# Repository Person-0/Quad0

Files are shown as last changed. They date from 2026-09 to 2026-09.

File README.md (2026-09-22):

# **Quad0**

*quadcopter with a custom flight controller, firmware that supports both brushed and brushless motors*

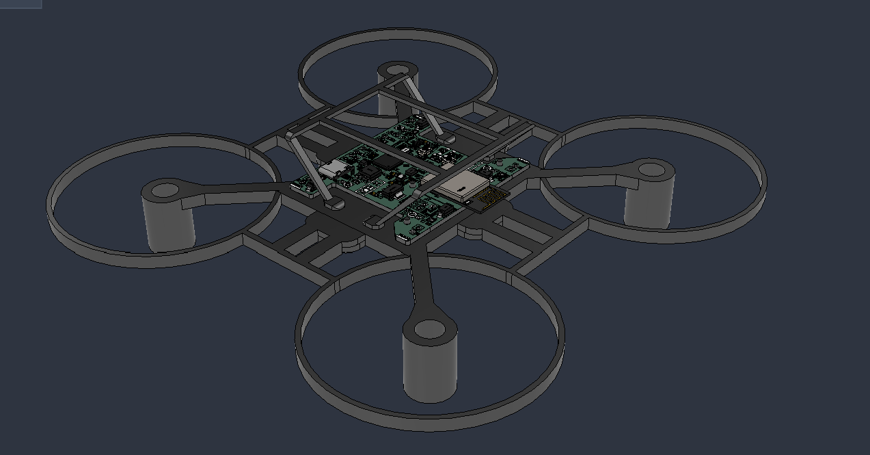
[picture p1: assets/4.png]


## **The Idea**
This is a custom flight controller with minimal stuff required to fly a quadcopter on-board, supporting both brushless and brushed motors.

Onboard components include:

- `RP2350A` Microcontroller Unit
- **IMU**:
    - `ICM-42688-P` Accelerometer & Gyroscope
    - `DPS368XTSA1` Barometer
    - `BMM150` Magnetometer

- MOSFET motor drivers (`DMN2024UFDF-7`) for brushed motors
- Pads to connect brushed / brushless motors
- Support for `ESP01 WiFi module` for brushed mode OR any radio receiver that supports SBUS or similar protocols for brushless mode

The board will be designed in a way such that it can fly with standard *8520 coreless motors* and a tiny lipo battery for brushed mode.

As for the brushless mode, I will be targeting `2204` size brushless motors with a `5inch` prop size, ~5inch frame configuration.

> For building, skip to [Build instructions](#build-instructions) section.

## **PCB**

The PCB 3D preview looks like this:

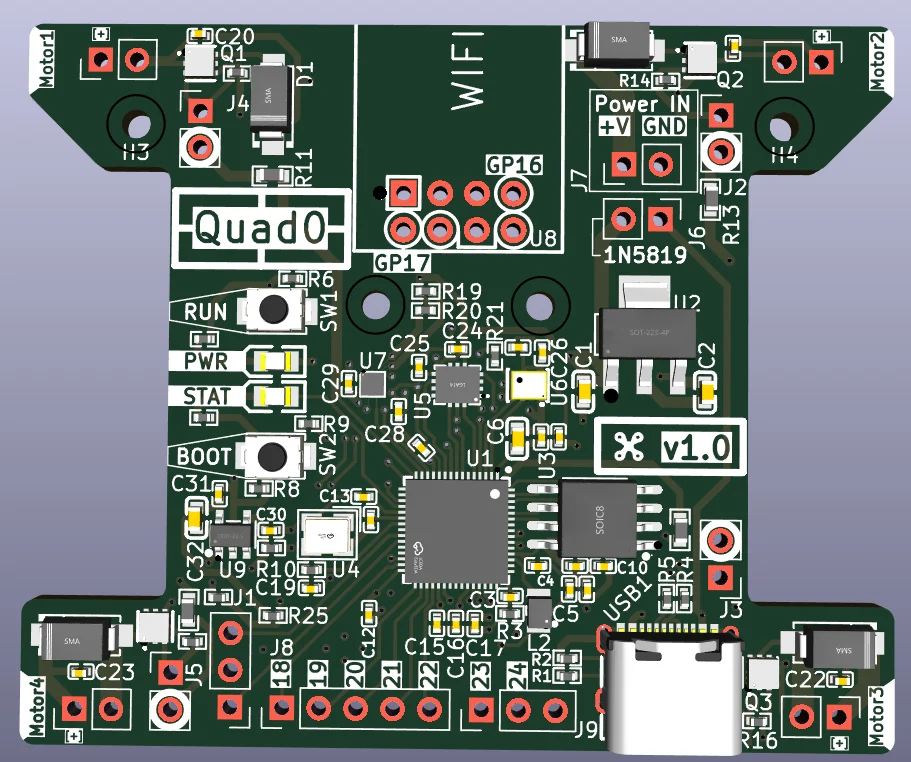
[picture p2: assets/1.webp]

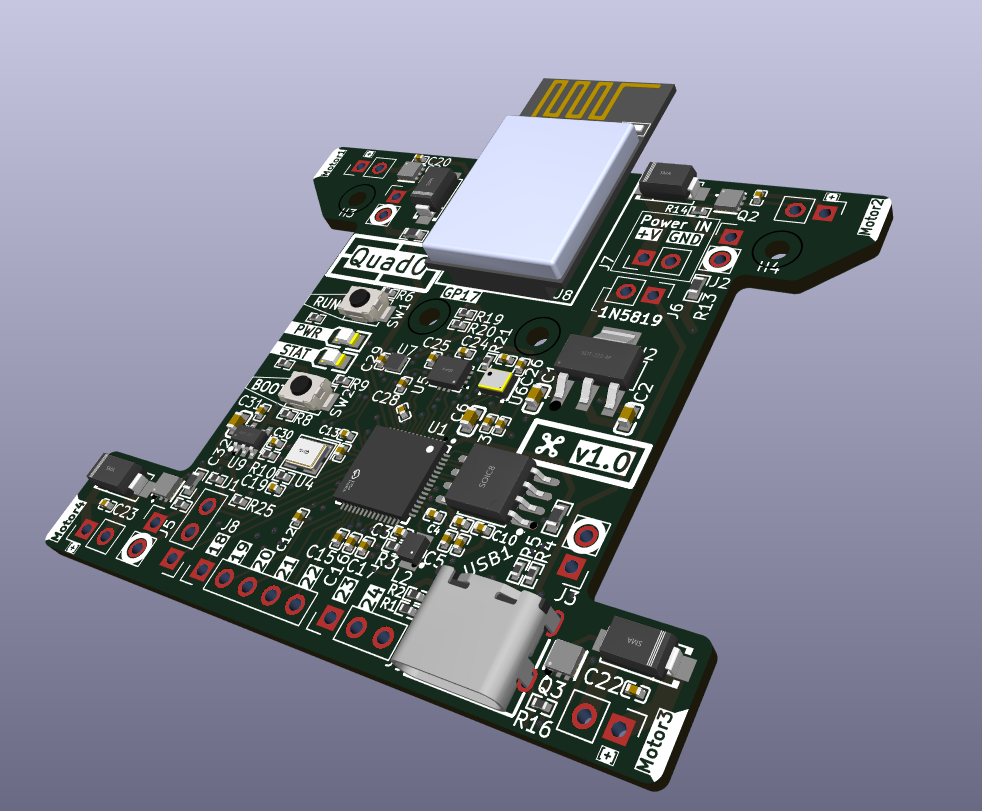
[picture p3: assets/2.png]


## **Schematics**

> *[Right Click >> Open in new tab] on the image to view properly.*

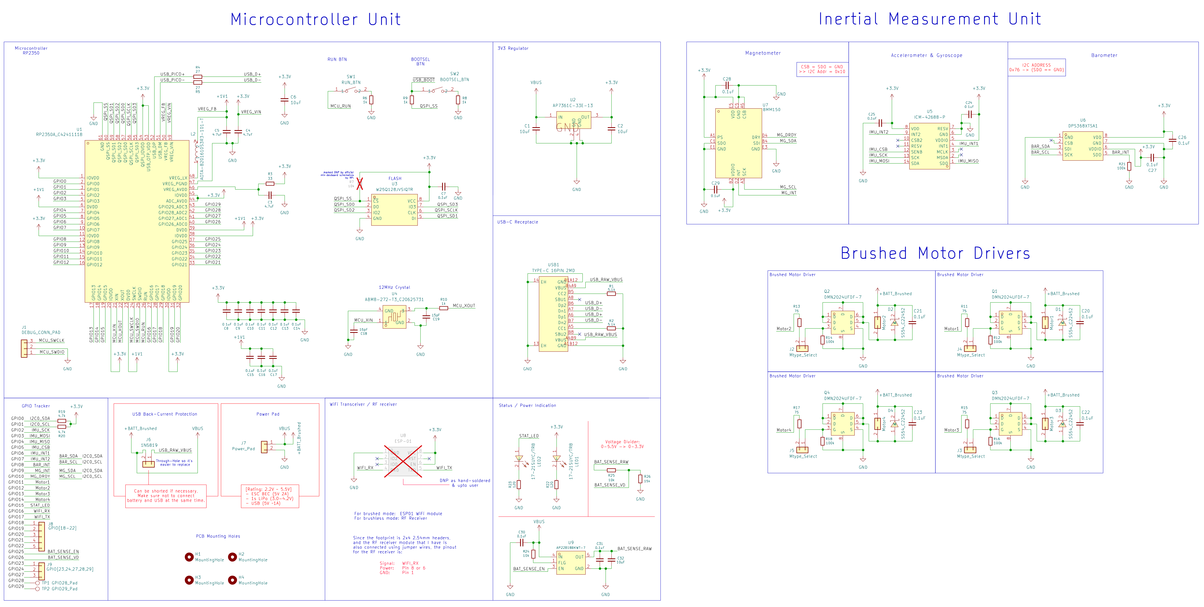
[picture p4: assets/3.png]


> Note that the PCB and schematic files can be opened using KiCAD. They are located in the `/PCB/Quad0` directory inside this repository.

Steps for viewing the PCB schematics and layout:
- Open KiCAD
- Click **File** (top left) >> **Open Project**
- Navigate to the the repository's saved destination,
- Open **/PCB/Quad0** directory
- Select the file `Quad0.kicad_pro`

## Brushed / Brushless Switch

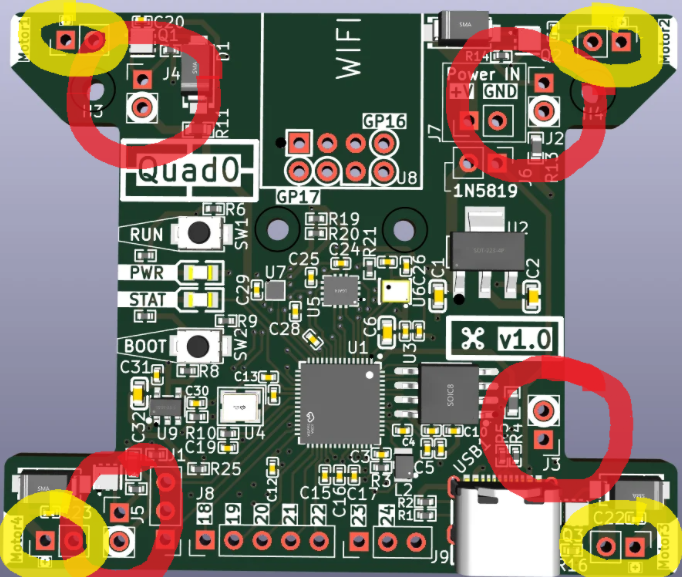
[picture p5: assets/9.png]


- **Yellow**: Brushed motor connectors
- **Red**: Brushed / Brusheless Mode selection connector

**For Brushed:** Short both pads together using solder or by soldering 2.54mm headers and adding jumper.

**For Brushless:** Un-short both pads if shorted, connect ESC signal pin to the pad marked with the thick white circle.

Each Mode selection connector is placed closest to the motor output it controls.

## **CAD Frame**
> View [/CAD](./CAD/) directory for `.f3d` and `.step` files.

The frame for brushed version of the quadcopter was designed in Fusion360 and looks like this:


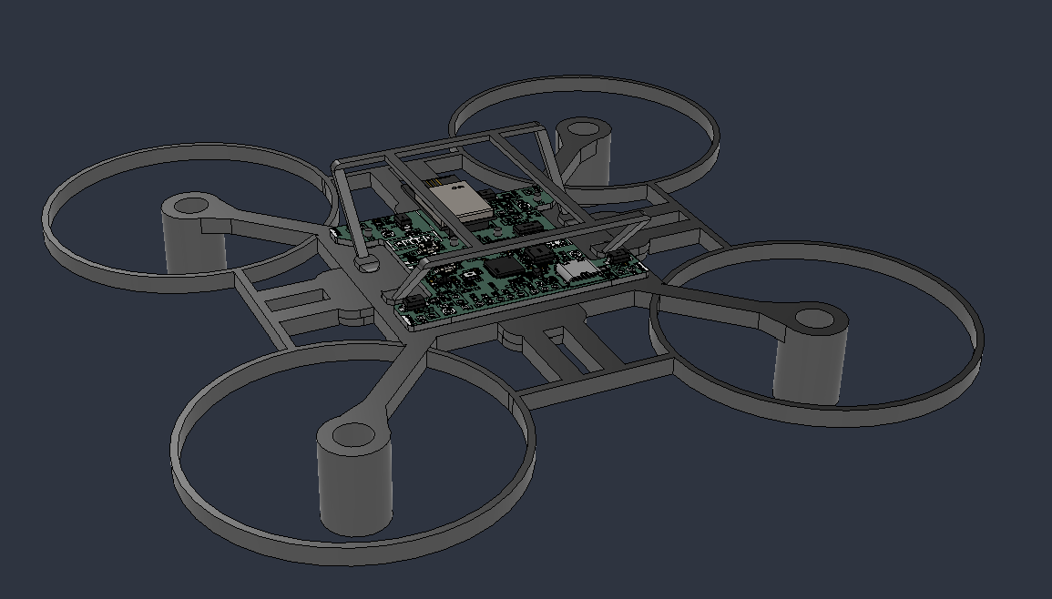
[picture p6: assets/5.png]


**The frame is divided into 3 separate parts:**

- **Main Frame:**

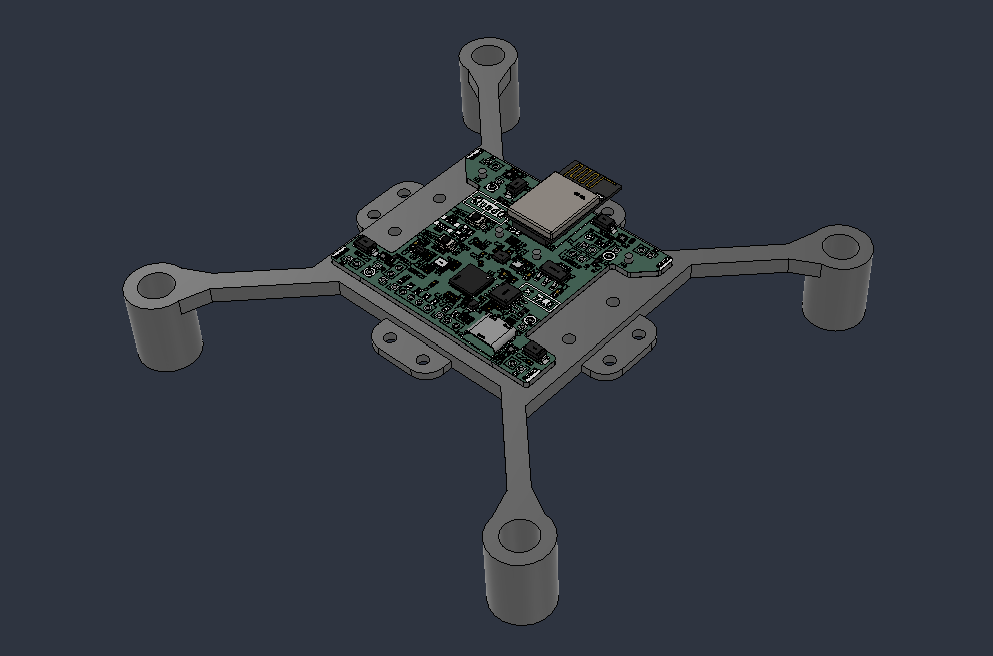
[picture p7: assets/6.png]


- **Duct Body:**

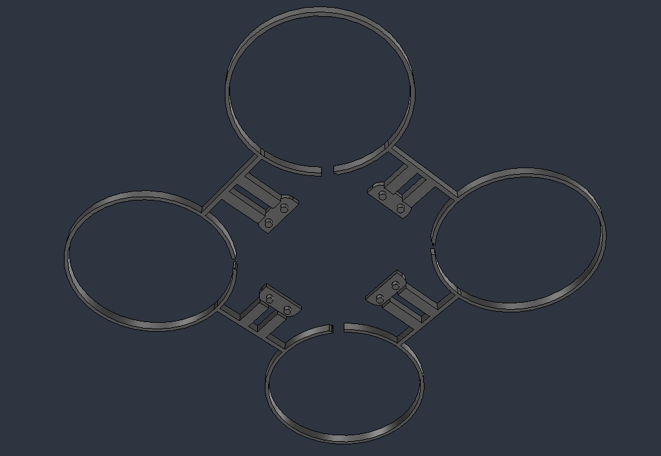
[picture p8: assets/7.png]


- **Cover:**

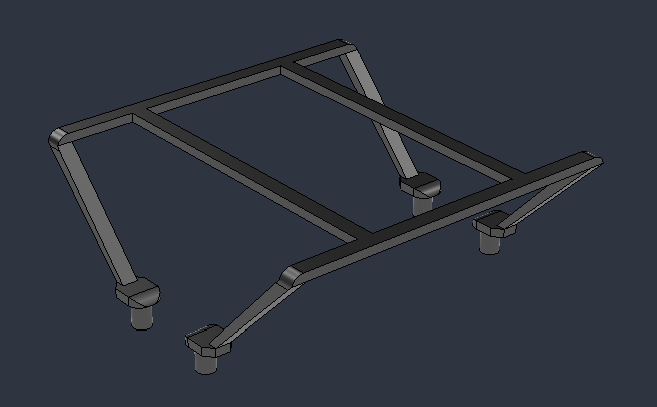
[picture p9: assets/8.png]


All the parts are made to friction-fit together using cylindrical extrusions and holes, the reason being to minimize the weight of the frame as using screws would add a LOT of weight. The friction fits would allow for either the cover or duct body to be omitted incase they are adding too much weight.

## **Firmware**

*Please checkout the [/Firmware](./Firmware/) directory to view the firmware source, current state and compiling / flashing instructions.*

> Note that the hardware is also [fully supported](https://betaflight.com/blog/2025/10/10/RP2350%20Lands%20in%20Betaflight) by [Betaflight](https://betaflight.com/). Instructions on how to setup betaflight will be provided after I physically test it myself to know what works.

## **Ordering Parts, PCBA**
1. **PCBA**

Files required (gerber, bom, cpl) for ordering PCB Assembly from JLCPCB are available in [PCB/Ordering/](./PCB/Ordering/) directory.

The grand total for this comes out to be at `$108.95`, including `$9.86` for shipping. This cost can be brought down using coupon codes and also using JLCPCB'S desktop app: JLCONE.

This is after minimizing extended components usage and using basic PCBA (cheapest option). The PCB quantity and PCBA quantity is the MOQ (minimum order quantity): 5, 2 respectively.

**Cart Screenshot:**

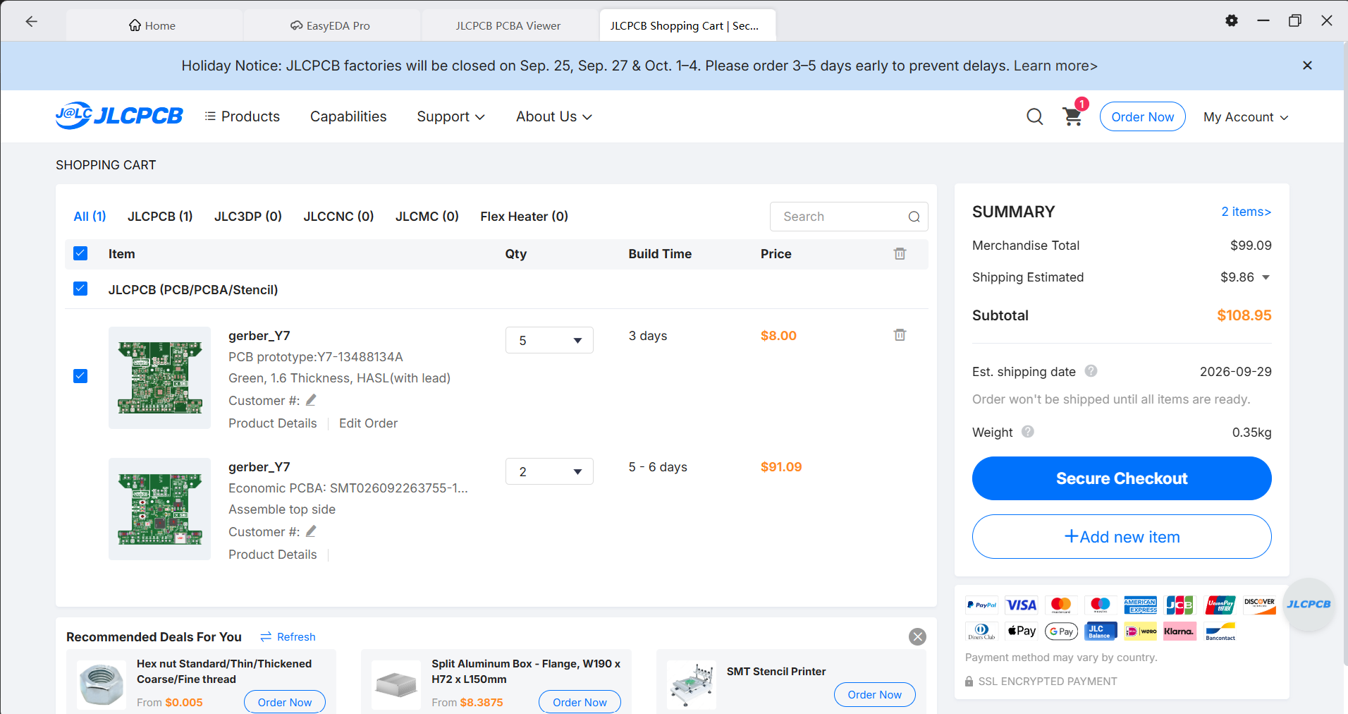
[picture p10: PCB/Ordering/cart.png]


2. **Other components**

Components required other than the ones that the PCBA covers are the following (for brushed mode):
- 4x Coreless Motors
- 4x 65mm propellers (2CW + 2CCW)
- 1x 1N5819 Diode (6V version recommended)
- 1x 3.7v tiny LiPo battery (+ a charger for it if you do not have one). Recommended capacity ~350-500mAh, try to minimize weight
- 1x ESP-01 WiFi Module
- 2.54mm header pins as required (only if you need them, otherwise you can directly solder the wires to the pads)

### **BOM** (Region: India)
---
| S.No. | Item Name | Item Description | URL | Qty | Unit Price ($) | Effective Price ($) |
|---:|---|---|---|---:|---:|---:|
| 1 | JLCPCB Order | 5x PCB + 2x PCBA | - | 1 | 99.09 | 99.09 |
| 2 | JLCPCB Shipping | Shipping costs | - | 1 | 9.86 | 9.86 |
| 3 | 8520 Coreless Brushed Motor | 8520 Coreless motor | https://makerbazar.in/products/magnetic-micro-coreless-motor-for-drones-quadcopters-rc?variant=44950426812656 | 4 | 0.72 | 2.88 |
| 4 | 65mm 2 Blade Toothpick Propeller 1mm Shaft Pitch 1.3" Clear Red (4 Pair CW+CCW) | 65mm Propeller | https://evelta.com/gemfan-65mm-2-blade-toothpick-propeller-1mm-red/?sku=479-PMPC65S-R1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 | 1 | 2.20 | 2.20 |
| 5 | 1N5819 40V 1A Schottky Diode - Pack of 10 | Diode for reverse polarity protection | https://makerbazar.in/products/1n5819-schottky-diode-1a-40v-do-41?variant=48251131527408 | 1 | 0.20 | 0.20 |
| 6 | 3.7V 500mAH LiPo battery | 500 mAh LiPo battery | https://makerbazar.in/products/kp-drone-lipo-batteries-3-7v-rechargeable-battery-for-mini-rc-aircraft-quadcopters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 | 1 | 2.81 | 2.81 |
| 7 | ESP-01 ESP8266 Serial WIFI Transceiver Module | ESP01 WiFi module | https://makerbazar.in/products/esp8266-wifi-module-for-arduino?variant=31789289898080 | 1 | 1.41 | 1.41 |
| | | | | | **Total:** | **127.50** |

This does not include shipping costs for components other than PCB+PCBA, since that will differ from place-to-place.

## **Build Instructions**

The project build is divided into 4 parts:
1. PCB, Components ordering
2. Soldering external components onto the PCB
3. 3D printing the frame
4. Compiling, Flashing the firmware.

### 1.) PCB, Components Ordering
Please refer the [Ordering Parts, PCBA](#ordering-parts-pcba) section for this step.

### 2.) Soldering external components onto the PCB
Various components are required to be externally hand soldered onto the PCB. Focusing on the brushed mode, these are the components:
1. **Brushed Motors**: These need to be soldered to the motor pads at the corner ends of the PCB. Make sure that the Mode selection connector pads that are present near the motor connectors are shorted for brushed mode. This might require re-soldering to change motor polarity so keep that in mind.
2. **1N5819 Diode**: This needs to be soldered on the 2.54mm header pad with silkscreen marked as "1N5819". The cathode should be connected to the pad with the silkscreen square connected to the silkscreen text (This is the +BATT_Brushed pad).
3. **Battery Connector**: Marked as "Power IN" on the silkscreen with + and - symbols, either use JST style male-female connectors (preferred) or simple jumper wires. Solder the female connector to the PCB and the male one to the battery terminals. Ensure you can charge the battery easily and handle the LiPo batteries properly as they are extremely dangerous. Battery can be fixed using rubber bands or double-sided tape onto the backside of the frame. Make sure to center it as accurately as close to the Quad's centre-of-gravity, so as to ensure stable flight
4. **ESP-01**: Solder the ESP-01 module to the top footprint defined for it. You can refer the 3D frame render for orientation as it shows the correct way it needs to be placed. Your module most likely will already have headers soldered onto it, you just need to solder it onto the PCB.
5. **GPIO Pins (optional)**: At the bottom of the PCB, if needed, solder female header pins or just solder the extra components directly.

### 3.) 3D printing the frame + assembling
The following three `.step` files need to be 3d printed separately using a lightweight but sturdy material of your choice: (I will be testing it out myself, starting with PLA)
- [MainBody.step](./CAD/exports/MainBody.step)
- [DuctBody.step](./CAD/exports/DuctBody.step)
- [Cover.step](./CAD/exports/Cover.step)

After that, It is recommended to test the quad with just the MainBody and then progressively add the DuctBody, Cover. This helps to ensure that the drone actually flies and is not held down by the weight of the frame.

The PCB sits on the cylindrical extrusions defined for it (as shown in the preview images). You can add tiny foam/similar rings between the PCB and the plastic body to dampen motor vibrations. Use adhesive tape (or whatever you prefer) to firmly hold the PCB in place with the main body, while also making sure you do not add extra unnecessary weight.

### 4.) Compiling, Flashing the firmware
Please refer the [/Firmware](./Firmware/) directory for this step.

That's it!

## 😼💖

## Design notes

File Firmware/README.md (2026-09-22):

# **Quad0**: Firmware

This directory contains custom flight controller firmware for Quad0.

## Current State

The firmware is currently work-in-progress and will be updated as I build the project physically. Since this project requires extensive physical testing (Checks for current firmware, PID Tuning, runtime errors etc.), the firmware will be updated progressively as I test while building instead of doing everything before and then rewriting most of the stuff again (which would be a huge waste of time).

### Boot flow
1. MCU Powered-on, Stat LED initialized
2. Battery status checking logic initialized
3. Battery read, if equal-to or below 15%, boot halted with status indication
4. Other components initialized (WiFI Rx, IMU, Motors)
5. Main loop starts and calls all methods at every iteration

### What is expected to work?
The following stuff is expected to happen on powering the MCU, with sufficient battery charge (or USB power):
- MCU Boots
- Power LED lights up
- Status LED does not light up at all (battery charge is above 15%)
- All components are properly initialized, Status LED does not blink (no IMU error)
- Program flow proceeds to the main loop
- Status LED does not light up at all again (battery charge above 5%)

### What is left?
- Receiving Instructions from the WiFi receiver: will be done after ESP01 is confirmed to be working fine with the current initialization setup.
- Reading IMU sensors data: again, will be done after any errors that show up during IMU initialization after real world testing are fixed.
- Drone stabilization, calibration / PID Tuning: will be done after the previous two steps are complete.

### Status LED Indications

These are the error codes currently coded in the firmware. If these are displayed, it means the MCU encountered a fatal error and cannot continue normal operation.

- `2` blinks, `250ms` interval -> Battery percentage too low to boot or continue operation.
- `5` blinks, `250ms` interval -> IMU setup failed, check serial log for more info.

### Specific Error Codes
- IMU setup failed:
    - `Code` is available in serial console
    - `1`: barometer_test() returned false
    - `2`: magnetometer_test() returned false
    - `3`: icm_test() returned false (ICM-42688, Accelerometer + Gyro)

## Firmware Compiling / Flashing
- Install the [Raspberry Pi Pico VS Code extension](https://marketplace.visualstudio.com/items?itemName=raspberry-pi.raspberry-pi-pico)
- Clone this repository
- Open this folder (/firmware) in VS Code
- The extension will automatically detect your workspace and install necessary toolchains that will be used to compile the firmware
- Edit files if required
- Press `Compile` at the bottom bar to test whether the firmware compiles successfully
- Hold the boot tactile switch on the PCB while plugging it into your PC, this will allow us to flash the firmware
- Use the `Run` button next to the Compile button at the bottom bar to compile, flash the firmware. After the firmware is flashed, the board will auto reboot and you will see the results directly.

> Note that all pin definitions and configuration variables are defined in the [config.h](./config.h) file.

## Special Notes

- Use the official Raspberry Pi Pico VS Code extension to build or flash the firmware as it will save you lots of time and config messes.

## Pin Definitions
Available in [config.h](./config.h).

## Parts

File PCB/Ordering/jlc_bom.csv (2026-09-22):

Designator | Qty | Value | DNP | Exclude from BOM | Exclude from Board | Footprint | Datasheet | MPN | Manufacturer | LCSC Part | Description
C1,C2,C6,C32 | 4 | 10uF |  |  |  | easyeda2kicad:C0603 | https://jlc-prod-smt.oss-eu-central-1.aliyuncs.com/smtDataManualFile/8579707107916242944-C19702.pdf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 | CL10A106KP8NNNC | Samsung Electro-Mechanics | C19702 | Unpolarized capacitor, small symbol
C3,C4,C5 | 3 | 4.7uF |  |  |  | easyeda2kicad:C0402 | https://jlc-prod-smt.oss-eu-central-1.aliyuncs.com/smtDataManualFile/8588919214354124800-C77004.pdf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 | GRM155R61A475KEAAD | Murata Electronics | C77004 | Unpolarized capacitor, small symbol
C7,C8,C9,C10,C11,C12,C13,C14,C15,C16,C17,C20,C21,C22,C23,C24,C25,C26,C27,C28,C29,C30,C31 | 23 | 0.1uF |  |  |  | easyeda2kicad:C0402 | https://jlc-prod-smt.oss-eu-central-1.aliyuncs.com/smtDataManualFile/8579707269992677376-C1525.pdf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 | CL05B104KO5NNNC | Samsung Electro-Mechanics | C1525 | Unpolarized capacitor, small symbol
C18,C19 | 2 | 15pF |  |  |  | easyeda2kicad:C0402 | https://jlc-prod-smt.oss-eu-central-1.aliyuncs.com/smtDataManualFile/8755234992119263232-C106997.pdf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 | CC0402JRNPO9BN150 | YAGEO | C106997 | Unpolarized capacitor, small symbol
D1,D2,D3,D4 | 4 | SS54_C22452 |  |  |  | easyeda2kicad:SMA_L4.4-W2.8-LS5.4-R-RD | https://lcsc.com/product-detail/Schottky-Barrier-Diodes-SBD_SS54_C22452.html | SS54 | MDD(辰达半导体) | C22452 | SS54
H1,H2,H3,H4,J1,J2,J3,J4,J5,J6,J7,J8,J9,Motor1,Motor2,Motor3,Motor4,R7,TP1,TP2 | 20 | 10k,1N5819,DEBUG_CONN_PAD,GPIO28_Pad,GPIO29_Pad,GPIO[18-22],GPIO[23,24,27,28,29],MountingHole,Mtype_Select,Power_Pad,motor | DNP | Excluded from BOM |  | Connector_PinHeader_2.54mm:PinHeader_1x02_P2.54mm_Vertical,Connector_PinHeader_2.54mm:PinHeader_1x03_P2.54mm_Vertical,Connector_PinHeader_2.54mm:PinHeader_1x05_P2.54mm_Vertical,MountingHole:MountingHole_2mm,TestPoint:TestPoint_Pad_D1.0mm | ~ |  |  |  | Generic connector, double row, 02x01, this symbol is compatible with counter-clockwise, top-bottom and odd-even numbering schemes., script generated (kicad-library-utils/schlib/autogen/connector/),Generic connector, single row, 01x02, script generated (kicad-library-utils/schlib/autogen/connector/),Generic connector, single row, 01x03, script generated (kicad-library-utils/schlib/autogen/connector/),Generic connector, single row, 01x05, script generated (kicad-library-utils/schlib/autogen/connector/),Mounting Hole without connection,Resistor, small symbol,test point
L2 | 1 | AOTA-B201610S3R3-101-T |  |  |  | easyeda2kicad:IND-SMD_L2.0-W1.6_AOTA-B201610S3R3-101-T | https://www.lcsc.com/datasheet/C42411119.pdf | AOTA-B201610S3R3-101-T | ABRACON | C42411119
LED1,LED2 | 2 | 17-21SUYC/TR8 |  |  |  | easyeda2kicad:LED0805-R-RD | https://lcsc.com/product-detail/Light-Emitting-Diodes-LED_Yellow-light-0805-Highlighted_C2296.html | KT-0805黄灯 | KENTO | C2296 | 0805
Q1,Q2,Q3,Q4 | 4 | DMN2024UFDF-7 |  |  |  | easyeda2kicad:DFN2020MD-6_L2.0-W2.0-P0.65-BL | https://www.lcsc.com/datasheet/C5248840.pdf | DMN2024UFDF-7 | DIODES(美台) | C5248840
R1,R2 | 2 | 5.1k |  |  |  | easyeda2kicad:R0402 | https://jlc-prod-smt.oss-eu-central-1.aliyuncs.com/smtDataManualFile/8579706035999215616-C25905.pdf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 | 0402WGF5101TCE | UNI-ROYAL(Uniroyal Elec) | C25905 | Resistor, small symbol
R3 | 1 | 33 |  |  |  | easyeda2kicad:R0402 | https://jlc-prod-smt.oss-eu-central-1.aliyuncs.com/smtDataManualFile/8579706024414412800-C25105.pdf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 | 0402WGF330JTCE | UNI-ROYAL(Uniroyal Elec) | C25105 | Resistor, small symbol
R4,R5 | 2 | 27 |  |  |  | easyeda2kicad:R0402 | https://jlc-prod-smt.oss-eu-central-1.aliyuncs.com/smtDataManualFile/8586178044432158720-C25100.pdf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 | 0402WGF270JTCE | UNI-ROYAL(Uniroyal Elec) | C25100 | Resistor, small symbol
R6,R8,R9,R10 | 4 | 1k |  |  |  | easyeda2kicad:R0402 | https://jlc-prod-smt.oss-eu-central-1.aliyuncs.com/smtDataManualFile/8579705924159586304-C11702.pdf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 | 0402WGF1001TCE | UNI-ROYAL(Uniroyal Elec) | C11702 | Resistor, small symbol
R11,R13,R15,R17 | 4 | 75 |  |  |  | easyeda2kicad:R0603 | https://jlc-prod-smt.oss-eu-central-1.aliyuncs.com/smtDataManualFile/8579706081762992128-C4275.pdf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 | 0603WAF750JT5E | UNI-ROYAL(Uniroyal Elec) | C4275 | Resistor, small symbol
R12,R14,R16,R18,R21 | 5 | 100k |  |  |  | easyeda2kicad:R0402 | https://jlc-prod-smt.oss-eu-central-1.aliyuncs.com/smtDataManualFile/8579705919460069376-C25741.pdf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 | 0402WGF1003TCE | UNI-ROYAL(Uniroyal Elec) | C25741 | Resistor, small symbol
R19,R20 | 2 | 4.7k |  |  |  | easyeda2kicad:R0402 | https://jlc-prod-smt.oss-eu-central-1.aliyuncs.com/smtDataManualFile/8579705941362999296-C25900.pdf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 | 0402WGF4701TCE | UNI-ROYAL(Uniroyal Elec) | C25900 | Resistor, small symbol
R22,R23 | 2 | 120 |  |  |  | easyeda2kicad:R0402 | https://jlc-prod-smt.oss-eu-central-1.aliyuncs.com/smtDataManualFile/8579705960426246144-C25079.pdf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 | 0402WGF1200TCE | UNI-ROYAL(Uniroyal Elec) | C25079 | Resistor, small symbol
R24,R25 | 2 | 10k |  |  |  | easyeda2kicad:R0402 | https://jlc-prod-smt.oss-eu-central-1.aliyuncs.com/smtDataManualFile/8556212101494185984-C25744.pdf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 | 0402WGF1002TCE | UNI-ROYAL(Uniroyal Elec) | C25744 | Resistor, small symbol
R26 | 1 | 15k |  |  |  | easyeda2kicad:R0402 | https://jlc-prod-smt.oss-eu-central-1.aliyuncs.com/smtDataManualFile/8579705971406659584-C25756.pdf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 | 0402WGF1502TCE | UNI-ROYAL(Uniroyal Elec) | C25756 | Resistor, small symbol
SW1,SW2 | 2 | BOOTSEL_BTN,RUN_BTN |  |  |  | easyeda2kicad:SW-SMD_L3.9-W3.0-P4.45 | https://lcsc.com/product-detail/Tactile-Switches_XUNPU-TS-1088-AR02016_C720477.html | TS-1088-AR02016 | XUNPU(讯普) | C720477
U1 | 1 | RP2350A_C42411118 |  |  |  | easyeda2kicad:QFN-60_L7.0-W7.0-P0.40-TL-EP3.4 | https://www.lcsc.com/datasheet/C42411118.pdf | RP2350A | Raspberry Pi(树莓派) | C42411118
U2 | 1 | AP7361C-33E-13 |  |  |  | easyeda2kicad:SOT-223_L6.5-W3.5-P2.30-LS7.0-BR | https://lcsc.com/product-detail/New-Arrivals_Diodes-Incorporated-AP7361C-33E-13_C500795.html | AP7361C-33E-13 | DIODES(美台) | C500795
U3 | 1 | W25Q128JVSIQTR |  |  |  | easyeda2kicad:SOIC-8_L5.3-W5.3-P1.27-LS8.0-BL | https://lcsc.com/product-detail/FLASH_W25Q128JVSIQTR_C97521.html | W25Q128JVSIQ | Winbond(华邦) | C97521
U4 | 1 | ABM8-272-T3_C20625731 |  |  |  | easyeda2kicad:CRYSTAL-SMD_4P-L3.2-W2.5-BL | https://www.lcsc.com/datasheet/C20625731.pdf | ABM8-272-T3 | ABRACON | C20625731
U5 | 1 | ICM-42688-P |  |  |  | easyeda2kicad:LGA-14_L3.0-W2.5-P0.50-BL | https://www.lcsc.com/datasheet/C54308212.pdf | ICM-42688-P(TOKMAS) | Tokmas(托克马斯) | C54308212
U6 | 1 | DPS368XTSA1 |  |  |  | easyeda2kicad:LGA-8_L2.5-W2.0-P0.65-TR_DPS368 | https://www.lcsc.com/datasheet/C55090144.pdf | DPS368XTSA1(TOKMAS) | Tokmas(托克马斯) | C55090144
U7 | 1 | BMM150 |  |  |  | easyeda2kicad:WLCSP-12_L1.6-W1.6_BMM150 | https://lcsc.com/product-detail/Sensors_Bosch_BMM150_BMM150_C171681.html | BMM150 | Bosch(博世) | C171681
U8 | 1 | ESP-01 | DNP | Excluded from BOM |  | easyeda2kicad:WIFIM-TH_8P-L24.7-W14.4-P2.54 | https://lcsc.com/product-detail/WIFI-Modules_Ai-Thinker-ESP-01_C503581.html | ESP-01 | Ai-Thinker(安信可) | C503581
U9 | 1 | AP22818BKWT-7 |  |  |  | easyeda2kicad:TSOT-23-5_L2.9-W1.6-P0.95-LS2.8-BL | https://www.lcsc.com/datasheet/C5564097.pdf | AP22818BKWT-7 | DIODES(美台) | C5564097
USB1 | 1 | TYPE-C 16PIN 2MD |  |  |  | easyeda2kicad:USB-C-SMD_TYPE-C-16PIN-2MD-073 | https://www.lcsc.com/datasheet/C2765186.pdf | TYPE-C 16PIN 2MD(073) | SHOU HAN(首韩) | C2765186

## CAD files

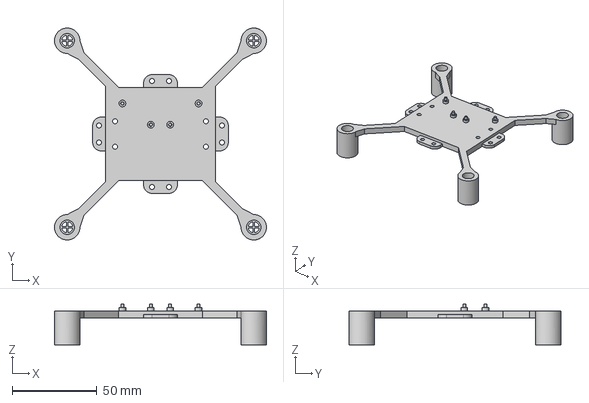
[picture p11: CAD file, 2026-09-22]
CAD/exports/MainBody.step
125.0 x 125.0 x 24.0 mm

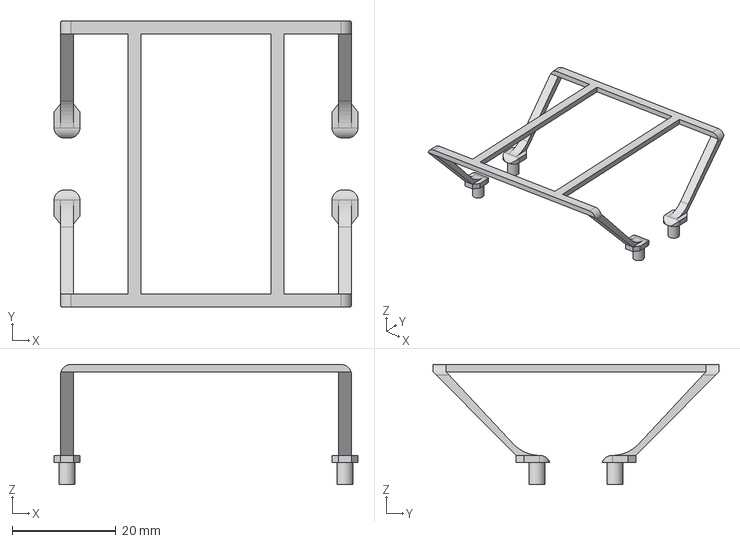
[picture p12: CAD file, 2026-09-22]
CAD/exports/Cover.step
58.5 x 55.0 x 23.1 mm

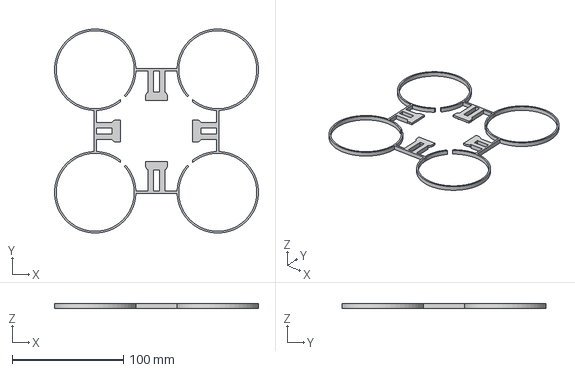
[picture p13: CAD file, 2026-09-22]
CAD/exports/DuctBody.step
183.1 x 183.1 x 4.20 mm

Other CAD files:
CAD/Quad0.f3d

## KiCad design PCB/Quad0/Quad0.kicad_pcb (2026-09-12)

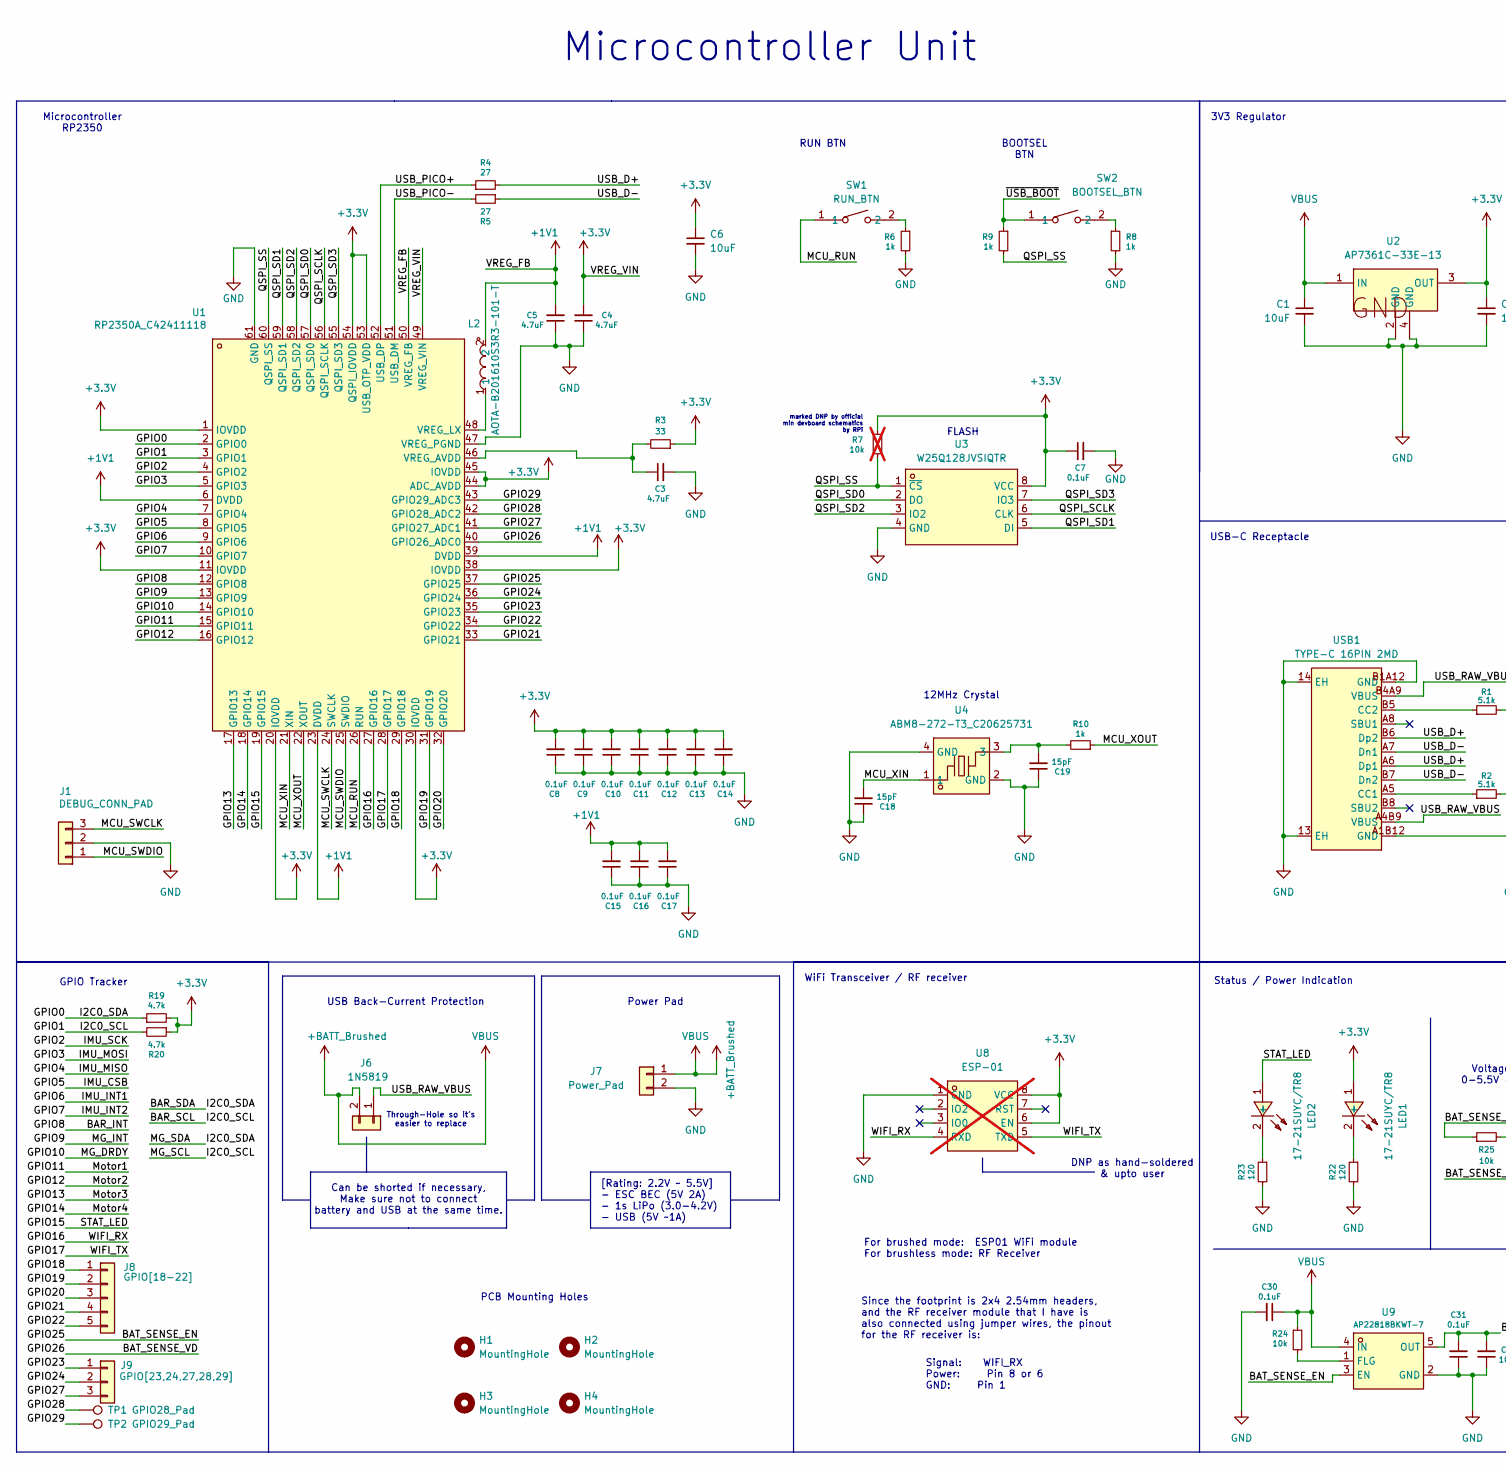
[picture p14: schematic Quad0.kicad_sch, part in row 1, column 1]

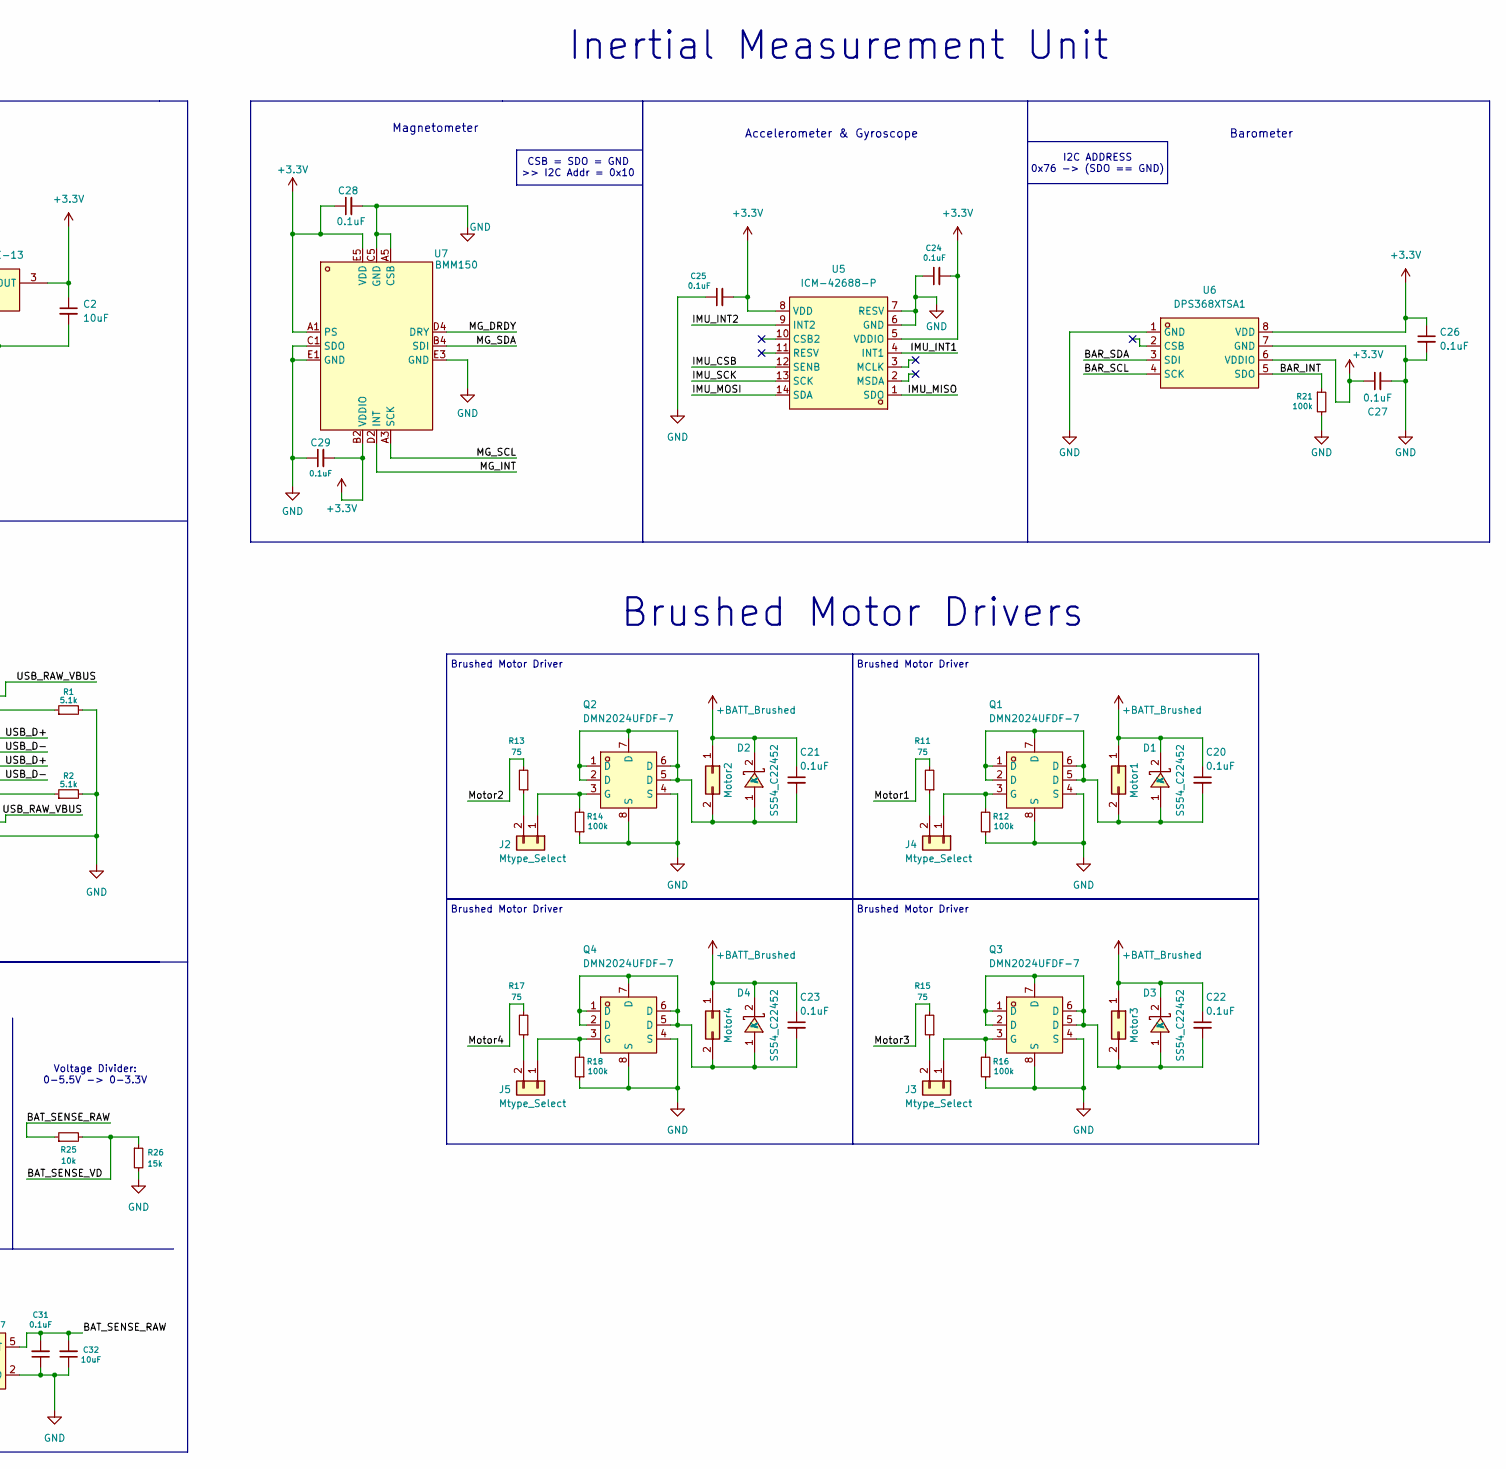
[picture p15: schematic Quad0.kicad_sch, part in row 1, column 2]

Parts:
C1, C2, C6, C32: 10uF; C0603; MPN CL10A106KP8NNNC; LCSC Part C19702
C3, C4, C5: 4.7uF; C0402; MPN GRM155R61A475KEAAD; LCSC Part C77004
C7, C8, C9, C10, C11, C12, C13, C14, C15, C16, C17, C20, C21, C22, C23, C24, C25, C26, C27, C28, C29, C30, C31: 0.1uF; C0402; MPN CL05B104KO5NNNC; LCSC Part C1525
C18, C19: 15pF; C0402; MPN CC0402JRNPO9BN150; LCSC Part C106997
D1, D2, D3, D4: SS54_C22452; SMA_L4.4-W2.8-LS5.4-R-RD; MPN SS54; LCSC Part C22452
H1, H2, H3, H4: MountingHole; MountingHole_2mm
J1: DEBUG_CONN_PAD; PinHeader_1x03_P2.54mm_Vertical
J2, J3, J4, J5: Mtype_Select; PinHeader_1x02_P2.54mm_Vertical
J6: 1N5819; PinHeader_1x02_P2.54mm_Vertical
J7: Power_Pad; PinHeader_1x02_P2.54mm_Vertical
J8: GPIO[18-22]; PinHeader_1x05_P2.54mm_Vertical
J9: GPIO[23,24,27,28,29]; PinHeader_1x03_P2.54mm_Vertical
L2: AOTA-B201610S3R3-101-T; IND-SMD_L2.0-W1.6_AOTA-B201610S3R3-101-T; MPN AOTA-B201610S3R3-101-T; LCSC Part C42411119
LED1, LED2: 17-21SUYC/TR8; LED0805-R-RD; MPN KT-0805黄灯; LCSC Part C2296
Motor1, Motor2, Motor3, Motor4: motor; PinHeader_1x02_P2.54mm_Vertical
Q1, Q2, Q3, Q4: DMN2024UFDF-7; DFN2020MD-6_L2.0-W2.0-P0.65-BL; MPN DMN2024UFDF-7; LCSC Part C5248840
R1, R2: 5.1k; R0402; MPN 0402WGF5101TCE; LCSC Part C25905
R3: 33; R0402; MPN 0402WGF330JTCE; LCSC Part C25105
R4, R5: 27; R0402; MPN 0402WGF270JTCE; LCSC Part C25100
R6, R8, R9, R10: 1k; R0402; MPN 0402WGF1001TCE; LCSC Part C11702
R7: 10k; not fitted
R11, R13, R15, R17: 75; R0603; MPN 0603WAF750JT5E; LCSC Part C4275
R12, R14, R16, R18, R21: 100k; R0402; MPN 0402WGF1003TCE; LCSC Part C25741
R19, R20: 4.7k; R0402; MPN 0402WGF4701TCE; LCSC Part C25900
R22, R23: 120; R0402; MPN 0402WGF1200TCE; LCSC Part C25079
R24, R25: 10k; R0402; MPN 0402WGF1002TCE; LCSC Part C25744
R26: 15k; R0402; MPN 0402WGF1502TCE; LCSC Part C25756
SW1: RUN_BTN; SW-SMD_L3.9-W3.0-P4.45; MPN TS-1088-AR02016; LCSC Part C720477
SW2: BOOTSEL_BTN; SW-SMD_L3.9-W3.0-P4.45; MPN TS-1088-AR02016; LCSC Part C720477
TP1: GPIO28_Pad; TestPoint_Pad_D1.0mm
TP2: GPIO29_Pad; TestPoint_Pad_D1.0mm
U1: RP2350A_C42411118; QFN-60_L7.0-W7.0-P0.40-TL-EP3.4; MPN RP2350A; LCSC Part C42411118
U2: AP7361C-33E-13; SOT-223_L6.5-W3.5-P2.30-LS7.0-BR; MPN AP7361C-33E-13; LCSC Part C500795
U3: W25Q128JVSIQTR; SOIC-8_L5.3-W5.3-P1.27-LS8.0-BL; MPN W25Q128JVSIQ; LCSC Part C97521
U4: ABM8-272-T3_C20625731; CRYSTAL-SMD_4P-L3.2-W2.5-BL; MPN ABM8-272-T3; LCSC Part C20625731
U5: ICM-42688-P; LGA-14_L3.0-W2.5-P0.50-BL; MPN ICM-42688-P(TOKMAS); LCSC Part C54308212
U6: DPS368XTSA1; LGA-8_L2.5-W2.0-P0.65-TR_DPS368; MPN DPS368XTSA1(TOKMAS); LCSC Part C55090144
U7: BMM150; WLCSP-12_L1.6-W1.6_BMM150; MPN BMM150; LCSC Part C171681
U8: ESP-01; WIFIM-TH_8P-L24.7-W14.4-P2.54; MPN ESP-01; LCSC Part C503581; not fitted
U9: AP22818BKWT-7; TSOT-23-5_L2.9-W1.6-P0.95-LS2.8-BL; MPN AP22818BKWT-7; LCSC Part C5564097
USB1: TYPE-C 16PIN 2MD; USB-C-SMD_TYPE-C-16PIN-2MD-073; MPN TYPE-C 16PIN 2MD(073); LCSC Part C2765186

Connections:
+1V1: C5.2, C15.2, C16.2, C17.2, L2.2, U1.6 (DVDD), U1.23 (DVDD), U1.39 (DVDD), U1.50 (VREG_FB)
+3.3V: C2.1, C4.2, C6.1, C7.1, C8.2, C9.2, C10.2, C11.2, C12.2, C13.2, C14.2, C24.2, C25.2, C26.1, C27.1, C28.1, C29.2, LED1.1 (+), R3.1, R7.1, R19.2, R20.1, U1.1 (IOVDD), U1.11 (IOVDD), U1.20 (IOVDD), U1.30 (IOVDD), U1.38 (IOVDD), U1.44 (ADC_AVDD), U1.45 (IOVDD), U1.49 (VREG_VIN), U1.53 (USB_OTP_VDD), U1.54 (QSPI_IOVDD), U2.3 (OUT), U3.8 (VCC), U5.5 (VDDIO), U5.8 (VDD), U6.6 (VDDIO), U6.8 (VDD), U7.A1 (PS), U7.B2 (VDDIO), U7.E5 (VDD), U8.6 (EN), U8.8 (VCC)
+BATT_Brushed: C1.1, C20.1, C21.1, C22.1, C23.1, C30.1, D1.2 (K), D2.2 (K), D3.2 (K), D4.2 (K), J6.2, J7.1, Motor1.1, Motor2.1, Motor3.1, Motor4.1, R24.1, U2.1 (IN), U9.4 (IN)
/BAR_INT: R21.1, U1.12 (GPIO8), U6.5 (SDO)
/BAR_SCL: R20.2, U1.3 (GPIO1), U6.4 (SCK), U7.A3 (SCK)
/BAR_SDA: R19.1, U1.2 (GPIO0), U6.3 (SDI), U7.B4 (SDI)
/BAT_SENSE_EN: U1.37 (GPIO25), U9.3 (EN)
/BAT_SENSE_RAW: C31.2, C32.2, R25.1, U9.5 (OUT)
/BAT_SENSE_VD: R25.2, R26.1, U1.40 (GPIO26_ADC0)
/GPIO2: U1.4 (GPIO2), U5.13 (SCK)
/GPIO3: U1.5 (GPIO3), U5.14 (SDA)
/GPIO4: U1.7 (GPIO4), U5.1 (SDO)
/GPIO5: U1.8 (GPIO5), U5.12 (SENB)
/GPIO6: U1.9 (GPIO6), U5.4 (INT1)
/GPIO7: U1.10 (GPIO7), U5.9 (INT2)
/GPIO9: U1.13 (GPIO9), U7.D2 (INT)
/GPIO10: U1.14 (GPIO10), U7.D4 (DRY)
/GPIO11: R11.2, U1.15 (GPIO11)
/GPIO12: R13.2, U1.16 (GPIO12)
/GPIO13: R15.2, U1.17 (GPIO13)
/GPIO14: R17.2, U1.18 (GPIO14)
/GPIO15: LED2.1 (+), U1.19 (GPIO15)
/GPIO16: U1.27 (GPIO16), U8.4 (RXD)
/GPIO17: U1.28 (GPIO17), U8.5 (TXD)
/GPIO18: J8.1, U1.29 (GPIO18)
/GPIO19: J8.2, U1.31 (GPIO19)
/GPIO20: J8.3, U1.32 (GPIO20)
/GPIO21: J8.4, U1.33 (GPIO21)
/GPIO22: J8.5, U1.34 (GPIO22)
/GPIO23: J9.1, U1.35 (GPIO23)
/GPIO24: J9.2, U1.36 (GPIO24)
/GPIO27: J9.3, U1.41 (GPIO27_ADC1)
/GPIO28: TP1.1, U1.42 (GPIO28_ADC2)
/GPIO29: TP2.1, U1.43 (GPIO29_ADC3)
/MCU_RUN: SW1.1, U1.26 (RUN)
/MCU_SWCLK: J1.3, U1.24 (SWCLK)
/MCU_SWDIO: J1.1, U1.25 (SWDIO)
/MCU_XIN: C18.2, U1.21 (XIN), U4.1
/MCU_XOUT: R10.1, U1.22 (XOUT)
/QSPI_SCLK: U1.56 (QSPI_SCLK), U3.6 (CLK)
/QSPI_SD0: U1.57 (QSPI_SD0), U3.2 (DO)
/QSPI_SD1: U1.59 (QSPI_SD1), U3.5 (DI)
/QSPI_SD2: U1.58 (QSPI_SD2), U3.3 (IO2)
/QSPI_SD3: U1.55 (QSPI_SD3), U3.7 (IO3)
/QSPI_SS: R7.2, R9.2, U1.60 (QSPI_SS), U3.1 (~CS)
/USB_D+: R4.2, USB1.A6 (Dp1), USB1.B6 (Dp2)
/USB_D-: R5.1, USB1.A7 (Dn1), USB1.B7 (Dn2)
/USB_PICO+: R4.1, U1.52 (USB_DP)
/USB_PICO-: R5.2, U1.51 (USB_DM)
/USB_RAW_VBUS: J6.1, USB1.A4B9 (VBUS), USB1.B4A9 (VBUS)
/~USB_BOOT: R9.1, SW2.1
GND: C1.2, C2.2, C3.2, C4.1, C5.1, C6.2, C7.2, C8.1, C9.1, C10.1, C11.1, C12.1, C13.1, C14.1, C15.1, C16.1, C17.1, C18.1, C19.1, C24.1, C25.1, C26.2, C27.2, C28.2, C29.1, C30.2, C31.1, C32.1, J1.2, J7.2, Q1.4 (S), Q1.8 (S), Q2.4 (S), Q2.8 (S), Q3.4 (S), Q3.8 (S), Q4.4 (S), Q4.8 (S), R1.2, R2.2, R6.2, R8.2, R12.1, R14.1, R16.1, R18.1, R21.2, R22.2, R23.2, R26.2, U1.47 (VREG_PGND), U1.61 (GND), U2.2 (GND), U2.4 (GND), U3.4 (GND), U4.2 (GND), U4.4 (GND), U5.6 (GND), U5.7 (RESV), U6.1 (GND), U6.7 (GND), U7.A5 (CSB), U7.C1 (SDO), U7.C5 (GND), U7.E1 (GND), U7.E3 (GND), U8.1 (GND), U9.2 (GND), USB1.13 (EH), USB1.14 (EH), USB1.A1B12 (GND), USB1.B1A12 (GND)
unnamed: C19.2, R10.2, U4.3
unnamed: C20.2, D1.1 (A), Motor1.2, Q1.1 (D), Q1.2 (D), Q1.5 (D), Q1.6 (D), Q1.7 (D)
unnamed: C21.2, D2.1 (A), Motor2.2, Q2.1 (D), Q2.2 (D), Q2.5 (D), Q2.6 (D), Q2.7 (D)
unnamed: C22.2, D3.1 (A), Motor3.2, Q3.1 (D), Q3.2 (D), Q3.5 (D), Q3.6 (D), Q3.7 (D)
unnamed: C23.2, D4.1 (A), Motor4.2, Q4.1 (D), Q4.2 (D), Q4.5 (D), Q4.6 (D), Q4.7 (D)
unnamed: J2.1, Q2.3 (G), R14.2
unnamed: J2.2, R13.1
unnamed: J3.2, R15.1
unnamed: J3.1, Q3.3 (G), R16.2
unnamed: J4.1, Q1.3 (G), R12.2
unnamed: J4.2, R11.1
unnamed: J5.1, Q4.3 (G), R18.2
unnamed: J5.2, R17.1
unnamed: LED1.2 (-), R22.1
unnamed: LED2.2 (-), R23.1
unnamed: R6.1, SW1.2
unnamed: R8.1, SW2.2
unnamed: C3.1, R3.2, U1.46 (VREG_AVDD)
unnamed: L2.1, U1.48 (VREG_LX)
unnamed: R24.2, U9.1 (FLG)
unnamed: R2.1, USB1.A5 (CC1)
unnamed: R1.1, USB1.B5 (CC2)

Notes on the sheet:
12MHz Crystal
Microcontroller Unit
Through-Hole so it's easier to replace
Brushed Motor Driver
WiFi Transceiver / RF receiver
Can be shorted if necessary, Make sure not to connect battery and USB at the same time.
Brushed Motor Drivers
marked DNP by official min devboard schematics by RPi
Voltage Divider: 0-5.5V -> 0-3.3V
DNP as hand-soldered & upto user
I2C ADDRESS 0x76 -> (SDO == GND)
RUN BTN
[Rating: 2.2V ~ 5.5V] - ESC BEC (5V 2A) - 1s LiPo (3.0-4.2V) - USB (5V ~1A)
Status / Power Indication
Barometer
Signal: WIFI_RX Power: Pin 8 or 6 GND: Pin 1
Since the footprint is 2x4 2.54mm headers, and the RF receiver module that I have is also connected using jumper wires, the pinout for the RF receiver is:
CSB = SDO = GND >> I2C Addr = 0x10
USB-C Receptacle
GPIO Tracker
3V3 Regulator
BOOTSEL BTN
Inertial Measurement Unit
USB Back-Current Protection
Accelerometer & Gyroscope
FLASH
Microcontroller RP2350
PCB Mounting Holes
Magnetometer
Power Pad
For brushed mode: ESP01 WiFi module For brushless mode: RF Receiver

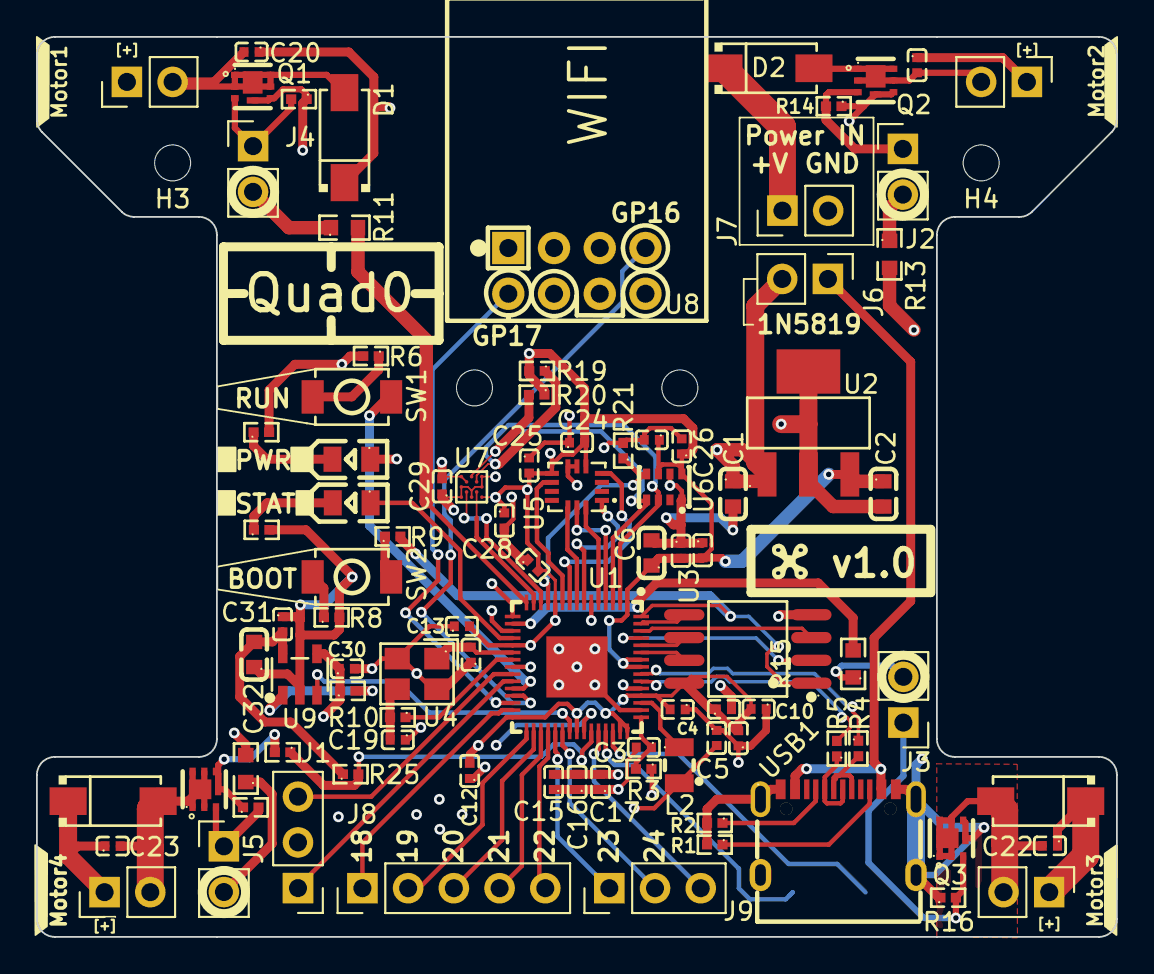
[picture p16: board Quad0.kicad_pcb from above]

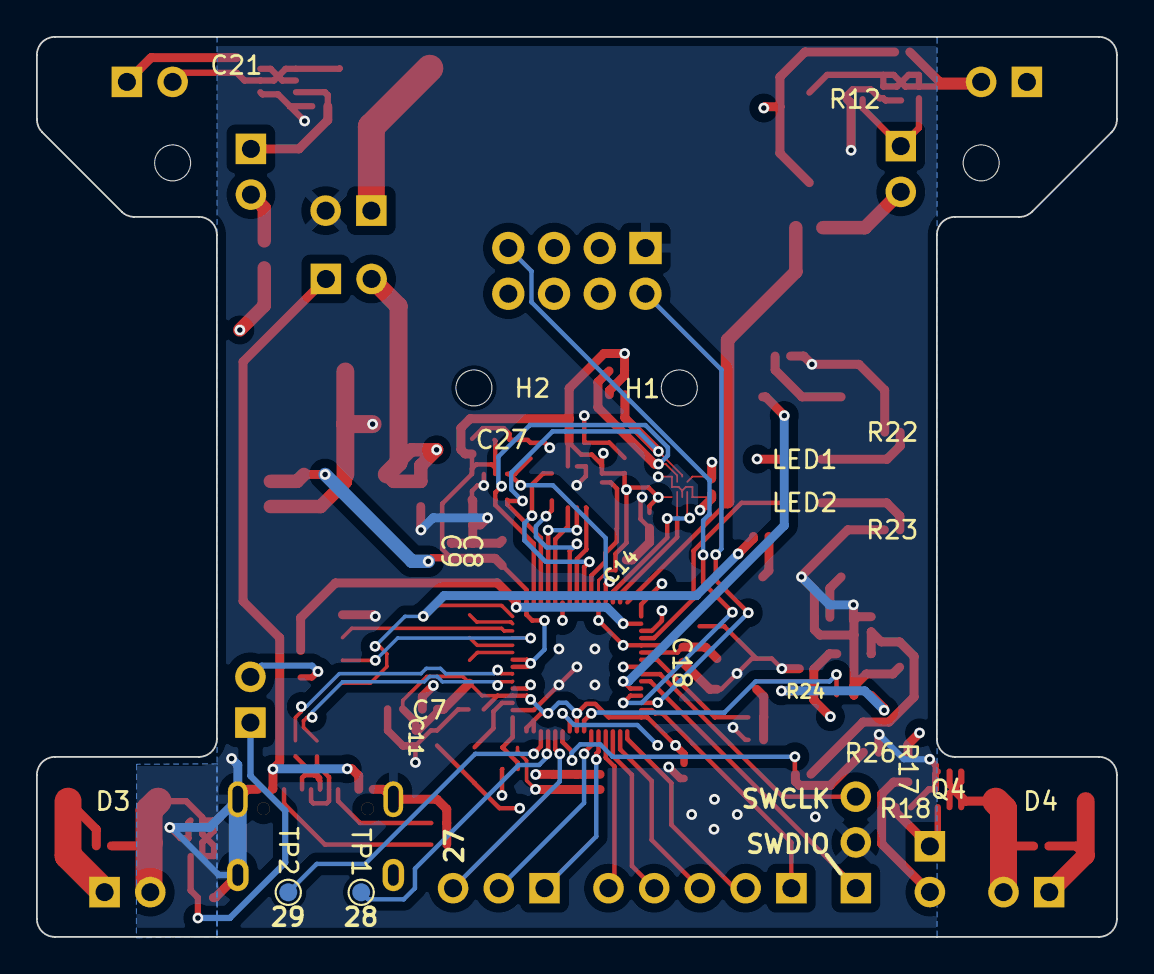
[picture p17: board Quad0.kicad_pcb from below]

Board: 4 copper layers, 60.0 x 50.0 mm, 99 parts (2 on the bottom side), 74 nets.

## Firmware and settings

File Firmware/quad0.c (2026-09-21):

#include <stdio.h>
#include "pico/stdlib.h"

#include "./config.h"
#include "./src/battery.h"
#include "./src/wifi.h"
#include "./src/imu.h"
#include "./src/motors.h"

void blink_stat(uint8_t times, uint8_t interval) {
    while(times > 0) {
        times -= 1;
        gpio_put(STAT_LED, 1);
        sleep_ms(interval / 2);
        gpio_put(STAT_LED, 0);
        sleep_ms(interval / 2);
    }
}

// returns 1 if battery too less, else 0
bool battery_status_check(uint8_t check) {
    if (battery_read() <= check) {
        blink_stat(2, 250);
        return 1;
    }
    return 0;
}

int main() {
    stdio_init_all();

    // stat led
    gpio_init(STAT_LED);
    gpio_put(STAT_LED, 0);

    // battery setup
    battery_setup();
    if (battery_status_check(BOOT_MIN_BAT)) return 0;

    // wifi setup
    wifi_setup();

    // imu setup (accelerometer/gyro + baro + magneto)
    uint8_t imu_setup_stat = imu_setup();
    if (imu_setup_stat > 0) {
        printf("IMU FAILED: %d\n", imu_setup_stat);
        blink_stat(5, 250);
        return 0;
    }

    // motor setup
    motor_setup();

    // main loop
    while (true) {

        wifi_task();

        // read battery in defined interval (in battery_status_check),
        // exit if check failed
        if (battery_should_read() && battery_status_check(MIN_BAT_REQ)) {
            break;
        }

    }

    return 0;
}

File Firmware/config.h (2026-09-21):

// ===============================
//      Pin Definitions
// ===============================

// Wifi / Receiver
#define WIFI_UART_BLOCK  1
#define WIFI_RX         16
#define WIFI_TX         17

#define I2C_BLK         i2c0 // for both Barometer & Magnetometer

// Barometer
#define BAR_SDA          0
#define BAR_SCL          1
#define BAR_INT          8

// Magnetometer
#define MG_SDA           0
#define MG_SCL           1
#define MG_INT           9
#define MG_DRDY         10

// Accelerometer / Gyroscope
#define ICM_SPI_BLK     spi0
#define ICM_SCK          2
#define ICM_MOSI         3
#define ICM_MISO         4
#define ICM_CSB          5
#define ICM_INT1         6
#define ICM_INT2         7

// Motor drivers / ESC connection
#define MOTOR1          11
#define MOTOR2          12
#define MOTOR3          13
#define MOTOR4          14

// Battery info
#define BAT_SENSE_EN    25
#define BAT_SENSE_VD    26

// MISC
#define STAT_LED        15


// ===============================
//      Battery Config
// ===============================

#define BOOT_MIN_BAT    15
#define MIN_BAT_REQ     5


// ===============================
//      Motor Config
// ===============================

#define MOTOR_MAX_VAL   6249


// ===============================
//      IMU Config
// ===============================

#define I2C_SPEED       400  // kHz
#define SPI_SPEED       1    // MHz

// Barometer
#define BAR_I2C_ADDR    0x77
#define BAR_PRODID      0x10
#define BAR_IDREG       0x8D

// Magnetometer
#define MG_I2C_ADDR     0x10
#define MG_PRODID       0x32
#define MG_IDREG        0x40

// Accelerometer / Gyroscope
#define ICM_WAI_REG     0x75
#define ICM_WAI_VAL     0x47

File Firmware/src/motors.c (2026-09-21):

#include "pico/stdlib.h"
#include "hardware/pwm.h"

#include "./motors.h"
#include "../config.h"

uint8_t MotorsIndexed[] = {MOTOR1, MOTOR2, MOTOR3, MOTOR4};

void motor_setup() {
    uint _slices[] = {
        pwm_gpio_to_slice_num(MOTOR1),
        pwm_gpio_to_slice_num(MOTOR2),
        pwm_gpio_to_slice_num(MOTOR3),
        pwm_gpio_to_slice_num(MOTOR4)
    };
    for (uint8_t i = 0; i < 4; i++) {
        gpio_set_function(MotorsIndexed[i], GPIO_FUNC_PWM);
        pwm_set_wrap(_slices[i], MOTOR_MAX_VAL);
        pwm_set_gpio_level(_slices[i], 0);
        pwm_set_enabled(_slices[i], true);
    }

}

/*
    motorNum: Motor Index (1-4)
    speed: 0 - MOTOR_MAX_VAL
*/
void motor_set_speed(uint8_t motorNum, uint16_t speed) {
    if (motorNum < 1 || motorNum > 4) return; // invalid motor num!
    pwm_set_gpio_level(MotorsIndexed[motorNum-1], speed);
}

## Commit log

2026-09-03 implemented basic rp2350 devboard schematics
    [Quad0.kicad_sch]
2026-09-03 follow the cap naming convention
    [Quad0.kicad_sch]
2026-09-05 added brushed motor drivers
    [Quad0.kicad_sch]
2026-09-05 added imu schematics, usb reverse current protection and wired everything to the appropriate gpio pins
    [Quad0.kicad_sch]
2026-09-05 added barometer
    [Quad0.kicad_sch]
2026-09-05 added wifi transceiver
    [Quad0.kicad_sch]
2026-09-06 added leds, fuel gauge schematic
    [Quad0.kicad_sch]
2026-09-07 shifted pcb files to internal subfolder
    [Quad0.kicad_pcb, Quad0.kicad_sch]
2026-09-07 added footprints and jlc part numbers for main board
    [Quad0.kicad_sch]
2026-09-08 updated readme with current info
2026-09-08 pcb layout rev1
    [Quad0.kicad_pcb, Quad0.kicad_sch]
2026-09-10 pcb layout + routing v2
    [OLD_Quad0.kicad_pcb, Quad0.kicad_pcb, Quad0.kicad_sch]
2026-09-10 removed old backup as it isnt needed anymore
    [OLD_Quad0.kicad_pcb]
2026-09-12 pcb art + routing finished
    [Quad0.kicad_pcb, Quad0.kicad_sch]
2026-09-12 added 3d model of PCB
    [Quad0.kicad_pcb]
2026-09-12 fixed incorrect component position
    [Quad0.kicad_pcb]
2026-09-19 frame is so cool
    [Quad0.f3d]
2026-09-20 current state info
2026-09-21 added battery check interval
2026-09-21 renamed pin defs to config
2026-09-21 added motor setup
2026-09-21 moved battery level check values to config.h, changed values for normal and boot check
2026-09-21 added magnetometer support
2026-09-21 added unused pin wip comment
2026-09-21 added pin def info
2026-09-22 add step file exports
    [Cover.step, DuctBody.step, MainBody.step]
2026-09-22 added assembly instructions, ordering information along with some other information.
    [jlc_bom.csv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]
2026-09-22 added battery placement info
